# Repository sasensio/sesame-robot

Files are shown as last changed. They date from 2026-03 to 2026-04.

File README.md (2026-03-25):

# The Sesame Robot Project 
___







sesame-cover

<p align="center">
  <a href="https://www.youtube.com/watch?v=NIgoQVQF_Ng">
    tutorial-button
  </a>
</p>

___

**Greetings, from your new best friend.**

Sesame is an accessible Open-Source robotics project based on the ESP32 microcontroller system, with an emphasis on expression and movement. 
This project is designed for makers and engineers of all skill levels! Sesame offers a dynamic platform designed to start working with walking robots. 
To build a sesame robot, you will need basic soldering skills, $50-60 in hardware components, access to a 3D printer, and a basic understanding of Arduino IDE.

This repository contains the CAD design files, STL files, build and wiring guides, and the base/expanded firmware for the ESP32-based controller. 
There is also some included debugging firmware that may be helpful in getting your Sesame up and running.

## Features

*   **Quadruped Design:** Uses 8 servo motors (2 per leg) to achieve roughly 8 total degrees of freedom.
*   **Emotive Display:** Features a 128x64 OLED screen acting as a reactive face that syncs with movement.
*   **Fully Printable:** Designed entirely for 3D printing in PLA with minimal supports.
*   **Network Connectivity:** Connect to your WiFi network for remote control and API access.
*   **JSON API:** RESTful API for programmatic control from Python, JavaScript, and more.
*   **Conversational Faces:** Expressive emotion library with talk variants for voice assistant projects.
*   **Sesame Studio:** New animation composer software to easily create custom movements.
*   **Sesame Companion App:** Python application for voice control and advanced interactions.
*   **Serial CLI:** Control the robot and trigger animations via a Serial Command Line Interface or the web UI.
*   **Pre-programmed Emotes:** Includes animations for Walking, Waving, Dancing, Pointing, Resting, and more.

## Watch the launch video on YouTube

<a href="https://www.youtube.com/watch?v=1UDsWkcQZhc">thumb-youtube</a>

## Join the Discord community
[https://discord.gg/JcFEPBbtEj
](https://discord.gg/JcFEPBbtEj)
___

## Getting Started

Follow these steps to build your own Sesame Robot:

### 1. Gather Parts 
Check the **[Bill of Materials (BOM)](hardware/bom/README.md)** for a complete list of required electronics and hardware.
*   Microcontroller: Lolin S2 Mini (recommended for DIY builds), Sesame Distro Board V2 (included in Build Kits, pre-flashed), or ESP32-DevKitC-32E with Distro Board V1 (legacy)
*   Actuators: 8x MG90 Servos
*   Power: 5V 3A source (USB-C PD for S2 Mini and V2 Distro Board, or battery + buck converter; see BOM for the 2× 10440 Li-ion + 2× AAA holder option)

### 2. Print Parts 
Download the STLs and follow the **[Printing Guide](hardware/printing/README.md)**.
*   Designed for PLA
*   Minimal supports required

### 3. Build & Wire 
Follow the **[Build Guide](docs/build-guide/README.md)** and **[Wiring Guide](docs/wiring-guide/README.md)** to assemble the frame and connect the electronics.

### 4. Flash Firmware 
Upload the code from the **[Firmware Directory](firmware/README.md)**.
*   Requires Arduino IDE
*   Configure WiFi AP settings

### 5. Create Animations 
Use **[Sesame Studio](software/sesame-studio/README.md)** to visually design poses and sequences for your robot.

sesame-wakeup-gif

---

## Software & Firmware

### Sesame Studio
Sesame Studio is a standalone desktop application included in `software/sesame-studio/`. It allows you to:
*   Visually pose the robot using a schematic interface.
*   Generate C++ code for servo angles automatically.
*   Sequence frames into complex animations.

[**> Go to Sesame Studio**](software/sesame-studio/README.md)

sesamestudio-preview

### Sesame Companion App
The Sesame Companion App is a Python-based application that enables advanced control and interaction with your robot over your local network. It leverages the new JSON API and network mode features to provide:
*   **Voice Assistant Integration:** Control Sesame with voice commands and see real-time emotional expressions.
*   **Remote Control:** Command your robot from anywhere on your local network.
*   **Face Control:** Change expressions dynamically based on conversation or context.
*   **API Examples:** Reference implementation for building your own integrations.

The Companion App works with robots running the latest firmware with network mode enabled.

[**> Go to Sesame Companion App Repository**](https://github.com/dorianborian/sesame-companion-app)

### Firmware
The ESP32 firmware (`sesame-firmware-main.ino`) handles the kinematics, face display, and WiFi control interface.
*   **Web UI:** Control the robot from your phone via the built-in Access Point.
*   **Custom Faces:** Add your own bitmaps (guide in firmware docs).

[**> Go to Firmware Docs**](firmware/README.md)

firmware-preview

---

## Contributing

This robot is a platform for building new features, cosmetics, tools, and ideas. Since the current firmware is a basic implementation, pull requests are very welcome for:
*   Kinematics improvements
*   New animations
*   Improved Web UI/UX
*   Sensor integration (Ultrasonic, Gyro, etc.)

I would also love to see forks of this project with new hardware, software, faces, etc. Be sure to send me a message if you end up building one, and I might feature you on my website or channel!
  
---

## Sesame Complete Build Kit Pre-orders available!
I am excited to announce that, after popular demand, Sesame Complete Build Kits are now available for pre-order! 

That's right, your little robot companion just got even easier to build. Each kit includes all the components you need to build a full Sesame Robot. With the included detailed instructions, guides, and resources, this kit is perfect for both seasoned Makers and beginners. Click the image below to learn more.

<a href="https://www.doriantodd.com/sesame/kit">kits-availible</a>

---

*Created by [Dorian Todd](https://www.doriantodd.com/). Need help with your Sesame Robot? Send me a message on Discord, my username is "starphee"*

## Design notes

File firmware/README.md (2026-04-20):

# Sesame Robot Firmware

This document provides technical information on the firmware architecture, control logic, and hardware abstraction layers used in the Sesame Robot.

>[!NOTE]
> The firmware is now organized into a modular structure with a main entry point and specialized header files for bitmaps, movement, and web assets. This makes customization much easier and the codebase cleaner.

## Table of Contents

- [How to Flash the Firmware](#how-to-flash-the-firmware)
- [Network Configuration](#network-configuration--connectivity)
- [API Reference](#api-reference)
  - [Legacy Web Endpoints](#legacy-web-endpoints)
  - [JSON API](#json-api-recommended-for-network-clients)
  - [Python Examples](#python-api-example)
  - [JavaScript Examples](#nodejsjavascript-example)
- [Advanced Integration Examples](#advanced-integration-examples)
  - [Voice Assistant Integration](#voice-assistant-integration)
  - [Home Automation](#home-automation-integration)
- [Idle Animation System](#idle-animation-system)
- [Firmware Architecture](#firmware-architecture)
- [Technical Implementation](#technical-implementation-overview)
- [Asset Pipeline & Face Customization](#asset-pipeline--face-customization)
- [Hardware Abstraction Layer](#hardware-abstraction-layer-hal)

## How to Flash the Firmware

> [!NOTE]
> **Sesame Build Kit Users:** Your Distro Board V2 comes pre-flashed with the latest firmware. You only need to flash firmware if you want to customize it or update to a newer version.

### Prerequisites
1. **Arduino IDE** (version 2.0 or higher recommended)
2. **ESP32 Board Support**: Install via Arduino IDE's Board Manager
   - Open Arduino IDE
   - Go to **File → Preferences**
   - Add to "Additional Board Manager URLs": `https://raw.githubusercontent.com/espressif/arduino-esp32/gh-pages/package_esp32_index.json`
   - Go to **Tools → Board → Boards Manager**
   - Search for "ESP32" and install "ESP32 by Espressif Systems" (v2.0.0 or higher)
3. **Required Libraries** (install via Library Manager):
   - `Adafruit SSD1306`
   - `Adafruit GFX Library`
   - **For direct-PWM boards** (Lolin S2 Mini, Distro Board V1/V2):
     - `ESP32Servo` **v3.0.9** (recommended)
   - **For camera boards** (ESP32-CAM, ESP32-S3-CAM):
     - `Adafruit PWM Servo Driver Library` (`Adafruit_PWMServoDriver`)

> [!IMPORTANT]
> Use **ESP32Servo v3.0.9** for direct-PWM boards. Newer releases currently have a known issue where writing to one servo can affect multiple channels ([madhephaestus/ESP32Servo#103](https://github.com/madhephaestus/ESP32Servo/issues/103)).
> Camera boards (ESP32-CAM, ESP32-S3-CAM) use PCA9685 instead of ESP32Servo and are not affected.

### Flashing Steps
1. **Connect your board** via USB to your computer
2. **Open the firmware**:
   - Open [sesame-firmware-main.ino](sesame-firmware-main.ino) in Arduino IDE
   - Make sure you have it in a folder with the same name.
   - Also include all of the .h header files.
3. **Select your board**:
   - Go to **Tools → Board**
   - For Lolin S2 Mini: Select "LOLIN S2 Mini"
   - For Sesame Distro Board V1: Select "ESP32 Dev Module"
   - For Sesame Distro Board V2: Select "ESP32S3 Dev Module"
   - **For ESP32-CAM**: Select "AI Thinker ESP32-CAM"
   - **For ESP32-S3-CAM**: Select "ESP32S3 Dev Module" (or the specific module variant)
4. **Configure board settings**:
   - **For Lolin S2 Mini**:
     - **Upload Speed**: 921600
     - **USB CDC On Boot**: "Enabled"
     - **Partition Scheme**: "Default 4MB with spiffs"
   - **For Distro Board V2 (ESP32-S3)**:
     - **USB CDC On Boot**: "Enabled" (Required for Serial Monitor)
     - **Flash Mode**: "QIO 80MHz"
     - **Partition Scheme**: "Default 4MB with spiffs"
   - **For ESP32-CAM**:
     - **Upload Speed**: 115200
     - **Flash Mode**: "DIO"
     - **Partition Scheme**: "Huge APP (3MB No OTA/1MB SPIFFS)"
5. **Select the correct port**:
   - Go to **Tools → Port** and select your ESP32's COM port
6. **Choose your board configuration** in the code:
   - Open [sesame-firmware-main.ino](sesame-firmware-main.ino)
   - Find the **Board Selection** block at the very top of the file (lines 1-10)
   - Uncomment **only** the `#define` that matches your board (leave the rest commented):
     ```cpp
     // #define BOARD_ESP32CAM        // AI-Thinker ESP32-CAM
     // #define BOARD_ESP32S3CAM      // Generic ESP32-S3-CAM (placeholder)
     // #define BOARD_DISTRO_V2       // Sesame Distro Board V2
     // #define BOARD_DISTRO_V1       // Sesame Distro Board V1
     // (leave all commented = Lolin S2 Mini default)
     ```
   - For camera boards (ESP32-CAM, ESP32-S3-CAM) also attach a **PCA9685** breakout to GPIO 26 (SDA) / GPIO 27 (SCL) — see [hal/README.md](hal/README.md) for wiring details.
7. **(Optional) Configure network mode**:
   - If you want the robot to connect to your WiFi network (for API access and remote control), edit the network configuration section (around line 17-22):
   ```cpp
   #define NETWORK_SSID "YourNetworkName"  // Your WiFi network name
   #define NETWORK_PASS "YourPassword"     // Your WiFi password
   #define ENABLE_NETWORK_MODE true        // Set to true to enable
   ```
   - Leave `ENABLE_NETWORK_MODE false` to use Access Point mode only
8. **Upload the firmware**:
   - Click the **Upload** button (→) in Arduino IDE
   - Wait for compilation and upload to complete
9. **Test the connection**:
   - Open Serial Monitor (**Tools → Serial Monitor**, set baud rate to 115200)
   - Reset the board - you should see startup messages and network information
   - The serial monitor provides individual motor control for testing and troubleshooting
   - **If using AP mode only**: Connect to the "Sesame-Controller-BETA" WiFi network (password: `12345678`) and navigate to any website
   - **If using network mode**: Look for the "Connected to network!" message in Serial Monitor, then access via `http://sesame-robot.local` or the displayed IP address

### Troubleshooting
- **Linux USB Permissions**: If your port isn't showing up or you get "Permission Denied", you likely need to add your user to the `dialout` group: `sudo usermod -a -G dialout $USER`. Log out and back in for changes to take effect.
- **Upload fails**: Try holding the BOOT button while uploading, or try a different USB cable. For S3-based boards, the "USB CDC On Boot" setting is critical for finding the port after a reset.
- **Port not found**: Install the appropriate USB drivers (CP210x for S2 Mini, CH340 for some ESP32 boards). Windows 10/11 usually includes these.
- **Robot not moving**: Check power supply and servo connections; increase `motorCurrentDelay` in web settings if brownouts occur
- **Can't connect to network**: 
  - Verify `ENABLE_NETWORK_MODE` is set to `true` and SSID/password are correct
  - Check Serial Monitor for connection status - look for "Connected to network!" or error messages
  - Ensure your WiFi network is 2.4GHz (ESP32 does not support 5GHz)
  - Try increasing the connection timeout in the code (currently 10 seconds / 20 attempts)
- **mDNS hostname not resolving**:
  - On Windows, install [Bonjour Print Services](https://support.apple.com/kb/DL999)
  - On Linux, ensure `avahi-daemon` is installed and running
  - Try accessing via IP address instead (check Serial Monitor for the assigned IP)
  - Some routers block mDNS traffic - check router settings or use IP address
- **API commands not working**:
  - Ensure you're sending POST requests to `/api/command` (not GET)
  - Verify `Content-Type: application/json` header is set
  - Check Serial Monitor for error messages and parsed command output
  - Test with a simple cURL command first to verify connectivity

## Firmware Architecture

The firmware is split into several key files to keep the logic organized and assets easy to manage:

- **[sesame-firmware-main.ino](sesame-firmware-main.ino)**: The main entry point containing the `setup()`, `loop()`, core system logic, network configuration, and API endpoints.
- **[face-bitmaps.h](face-bitmaps.h)**: A dedicated header for OLED face macros and raw bitmap data. Now includes extensive conversational faces for voice assistant integration.
- **[movement-sequences.h](movement-sequences.h)**: Definitions for all procedural movement and pose animations.
- **[captive-portal.h](captive-portal.h)**: Contains the HTML, CSS, and JS for the web-based remote control interface.

## Technical Implementation Overview

The firmware is built on the Arduino-ESP32 framework. Currently the firmware is running on a single-core event loop, and hardware-based PWM timers for precise motor control.

### PWM & Servo Kinematics
- **Timer Allocation**: The firmware uses `ESP32PWM::allocateTimer(n)` to reserve hardware timers 0-3. This prevents conflicts with other peripherals and ensuring high-resolution PWM signals (50Hz frequency). Due to the limited number of timers, you may experience network errors upon adding additional devices or calls to the firmware. For example, in a modded version of the robot, I tried adding two ESCs and their servo controll to the code, and the CPU ran out of internal timers and caused the captive portal to die. If you are experiencing network errors with your custom firmware, check the timer allocation.
- **Pulse Width Mapping**: Leg servos are mapped from degrees (0-180) to microseconds (732us to 2929us). This range is set to the maximum travel on most hobby servos with a 180 degree limit, but can be edited in the `servos[i].attach()` calls. If you are using motors with a larger range of motion, like 270 degree servos, you need to set the PWM mapping to a different length of microseconds. For 270 degree servos specifically I found (833us to 2167us) works.
- **Staggered Activation**: To prevent VCC rail collapse (brownout) caused by simultaneous inductive loads, the `setServoAngle` helper introduces a mandatory `motorCurrentDelay` (default 20ms) between sequential pulses. This delay should be tweaked to your power setup. If you have a strong dedicated power supply you can try setting it to zero. It can also be changed while running through the AP controller settings menu.
- **PCA9685 Auto-Release (Optional)**: For camera boards, `ENABLE_SERVO_AUTO_RELEASE` can release PWM outputs in rest mode to reduce idle servo current draw. This lowers holding power usage at the cost of holding torque while resting.

### Camera Stream & Recovery
- **Toggle Recovery Path**: Turning the camera OFF deinitializes and powers down the camera driver; turning it ON powers up, reinitializes with retries, and validates frame capture before stream resume.
- **Web Reconnect Robustness**: The web UI reconnects MJPEG with cache-busted URLs and retry cleanup to avoid stale stream sessions when toggling OFF→ON.
- **Adaptive FPS Hold**: Camera active frame timing now remains in high-rate mode for 30 seconds after movement stops, then returns to idle-rate streaming.
- **On-Board LED Control**: ESP32-CAM flash LED can be toggled from the web UI when supported by the selected board HAL.

### Communication & Networking Stack
- **Dual-Mode WiFi**: The ESP32 can simultaneously operate in both Access Point mode (for direct connections) and Station mode (connected to an existing network) using `WiFi.mode(WIFI_AP_STA)`.
- **SoftAP & Captive Portal**: The ESP32 initializes an Access Point using `WiFi.softAP()`. A `DNSServer` listens on UDP Port 53, using a wildcard "*" redirect to map all DNS queries to the internal gateway (`192.168.4.1`).
- **mDNS Service Discovery**: The firmware broadcasts `sesame-robot.local` via Multicast DNS (mDNS) using the `ESPmDNS` library, allowing network discovery without hardcoded IP addresses.
- **RESTful API Surface**: The `WebServer` handles both legacy URL-parameter endpoints and modern JSON-based API:
  - `/cmd?go=[dir]`: Legacy movement control
  - `/cmd?pose=[name]`: Legacy pose triggers
  - `/api/status`: JSON status endpoint (GET)
  - `/api/command`: JSON command endpoint (POST) - supports face-only updates and combined face+movement commands
  - `/getSettings` / `/setSettings`: Parameter configuration
- **Face-Only Command Support**: The `/api/command` endpoint intelligently detects face-only requests (no `command` field) and updates the display without triggering movement animations.
- **Non-Blocking Control Flow**: Instead of `delay()`, the firmware uses a custom `pressingCheck(String cmd, int ms)` function. This function polls `server.handleClient()` and `dnsServer.processNextRequest()` during animation frames, allowing for real-time interruptibility (e.g., immediate stop on button release). This pressingCheck protocol can be used for motion commands like walking to play each motion only when the button is held.

### Display & Graphics Subsystem
- **I2C Bus Hardware**: Utilizes the ESP32's hardware I2C controller at 400kHz (Fast Mode) for minimal latency when pushing full-frame buffers to the SSD1306 display.
- **Memory Management (`PROGMEM`)**: Large 128x64 bitmap arrays (1024 bytes per frame) are stored in Flash memory using the `PROGMEM` attribute.
- **Macro-Based Asset Management**: The firmware uses a `FACE_LIST` macro in [face-bitmaps.h](face-bitmaps.h) to automatically register and handle new faces, reducing the boilerplate required when adding animations.
- **Rendering Pipeline**: The `updateAnimatedFace()` function manages frame rates and sequence looping outside of the main movement logic to ensure smooth visual feedback even during complex movements.
- **Dynamic WiFi Info Overlay**: The `updateWifiInfoScroll()` function composites scrolling connection information over the face bitmap during the first 30 seconds of operation (before first input), drawing the face as background with a black bar and white text overlay for readability.
- **Idle Animation System**: Implements realistic idle behavior with randomized blinking (including double-blinks) and boomerang face animations, triggered automatically when no input is detected.

## Prerequisites & Development Environment

- **Board Support**: ESP32 by Espressif Systems (v2.0.0+ recommended). Lolin S2 Mini and ESP32-WROOM32 DevKitC are best supported.
- **Libraries**:
  - `ESP32Servo` **v3.0.9**: Low-level PWM timer management. (Pinned due to known multi-servo command leak in newer versions: [madhephaestus/ESP32Servo#103](https://github.com/madhephaestus/ESP32Servo/issues/103))
  - `Adafruit_SSD1306` & `Adafruit_GFX`: Buffer-based OLED rendering.
  - `ESPmDNS`: mDNS service discovery (included with ESP32 board support).
  - `DNSServer`: Captive portal DNS redirection (included with ESP32 board support).
  - `WebServer`: HTTP server implementation (included with ESP32 board support).
- **Tooling**: Arduino IDE 2.0+ recommended.

## Network Configuration & Connectivity

The firmware now supports **dual-mode WiFi operation**, allowing the robot to simultaneously act as an Access Point (for direct connections) and connect to your existing WiFi network (for integration with other devices and remote control).

### Access Point Mode (Default)
By default, the robot creates its own WiFi network:
- **SSID**: `Sesame-Controller-BETA`
- **Password**: `12345678` (Some devices may require you to change this if the default isn't connecting)
- **IP Address**: `192.168.4.1`

Connect to this network and navigate to any website to access the captive portal control interface. If you're having trouble connecting, try changing the password to something custom in the code's `#define AP_PASS` section.

### Network Mode (Optional)
To connect the robot to your home or office WiFi network:

1. **Enable Network Mode** in [sesame-firmware-main.ino](sesame-firmware-main.ino):
   ```cpp
   #define NETWORK_SSID "YourNetworkName"  // Your WiFi network name
   #define NETWORK_PASS "YourPassword"     // Your WiFi password
   #define ENABLE_NETWORK_MODE true        // Set to true to enable
   ```

2. **Flash the updated firmware** to your robot.

3. **Access via multiple methods**:
   - **mDNS Hostname**: `http://sesame-robot.local` (works on most devices)
   - **Network IP**: Check Serial Monitor at 115200 baud for the assigned IP address
   - **Still accessible via AP**: The robot maintains its Access Point even when connected to your network

### mDNS Discovery
The firmware includes an mDNS responder that broadcasts the hostname `sesame-robot.local` on your local network. This allows you to access the robot without knowing its IP address:

```bash
# Access from browser
http://sesame-robot.local

# Ping test
ping sesame-robot.local
```

**Note**: mDNS works natively on:
- macOS and iOS devices
- Linux with Avahi installed
- Windows 10+ (may require Bonjour service)

### Security Considerations

The firmware is designed for local network use and does not include authentication by default. When enabling network mode:

- **Local Network Only**: The robot responds to requests from any device on your network. Do not expose it to the internet without proper security measures.
- **No HTTPS**: Communication is unencrypted HTTP. Avoid transmitting sensitive data through the robot's API.
- **Access Point Password**: The default AP password is `12345678`. For production use, change `AP_PASS` in the firmware to a stronger password.
- **Trusted Networks**: Only connect your robot to trusted WiFi networks.

For enhanced security:
1. Change the default AP password to a strong, unique password
2. Use network segmentation (IoT VLAN) to isolate the robot from critical devices
3. Implement firewall rules to restrict access to specific IP addresses
4. Consider adding authentication headers in a custom firmware fork for production deployments

### WiFi Information Display
The robot's OLED screen now features an intelligent WiFi info system:
- **First 30 seconds**: If no input is received, WiFi connection information scrolls across the top of the display
- **After first input**: WiFi info disappears to show only faces
- **Dual-mode info**: When connected to both AP and network, displays both connection details

The scrolling text includes:
- Access Point SSID and IP
- Network name and IP (if connected)
- mDNS hostname
- Captive portal instructions

## API Reference

The firmware exposes both legacy web endpoints and a modern JSON-based API for programmatic control.

### Legacy Web Endpoints

These endpoints use URL parameters and are primarily used by the web interface:

#### Movement Control
```http
GET /cmd?go=forward
GET /cmd?go=backward
GET /cmd?go=left
GET /cmd?go=right
GET /cmd?stop
```

#### Pose Control
```http
GET /cmd?pose=wave
GET /cmd?pose=dance
GET /cmd?pose=rest
GET /cmd?pose=stand
# ... (see movement-sequences.h for all available poses)
```

#### Individual Motor Control
```http
GET /cmd?motor=1&value=90
# motor: 1-8 (motor number)
# value: 0-180 (angle in degrees)
```

#### Settings Management
```http
GET /getSettings
# Returns: {"frameDelay":100,"walkCycles":10,"motorCurrentDelay":20,"faceFps":8,
#           "cameraEnabled":true,"cameraLed":false,"cameraLedAvailable":true}

GET /setSettings?frameDelay=120&walkCycles=15&motorCurrentDelay=25&faceFps=10

# Camera controls
GET /setSettings?camera=1
GET /setSettings?camera=0

# Camera LED controls (when available)
GET /setSettings?camLed=1
GET /setSettings?camLed=0
```

### JSON API (Recommended for Network Clients)

The JSON API is designed for programmatic control from external devices, Python scripts, and IoT integrations.

#### Get Robot Status
```http
GET /api/status
```

**Response:**
```json
{
  "currentCommand": "forward",
  "currentFace": "walk",
  "networkConnected": true,
  "apIP": "192.168.4.1",
  "networkIP": "192.168.1.100"
}
```

#### Send Commands
```http
POST /api/command
Content-Type: application/json

{
  "command": "forward",
  "face": "walk"
}
```

**Response:**
```json
{
  "status": "ok",
  "message": "Command executed"
}
```

#### Face-Only Updates
Send a face change without triggering movement:

```http
POST /api/command
Content-Type: application/json

{
  "face": "happy"
}
```

**Response:**
```json
{
  "status": "ok",
  "message": "Face updated"
}
```

#### Stop Command
```http
POST /api/command
Content-Type: application/json

{
  "command": "stop"
}
```

### Available Commands

**Movement Commands:**
- `forward`, `backward`, `left`, `right` - Continuous movement (loops until stopped)
- `stop` - Immediately stop current movement

**Pose Commands (one-shot animations):**
- `rest`, `stand`, `wave`, `dance`, `swim`, `point`
- `pushup`, `bow`, `cute`, `freaky`, `worm`, `shake`
- `shrug`, `dead`, `crab`

**Available Faces:**
- Movement faces: `walk`, `rest`, `stand`, `dance`, `wave`, etc.
- Conversational faces: `happy`, `sad`, `angry`, `surprised`, `sleepy`, `love`, `excited`, `confused`, `thinking`
- Talk variants: `talk_happy`, `talk_sad`, `talk_angry`, etc.
- Special: `idle`, `idle_blink`, `default`

### Python API Example

```python
import requests
import time

# Robot IP or hostname
robot_url = "http://sesame-robot.local"

# Get status
response = requests.get(f"{robot_url}/api/status")
status = response.json()
print(f"Current face: {status['currentFace']}")

# Make robot wave and show happy face
requests.post(f"{robot_url}/api/command", json={
    "command": "wave",
    "face": "happy"
})

time.sleep(3)

# Just change face without moving
requests.post(f"{robot_url}/api/command", json={
    "face": "excited"
})

# Stop movement
requests.post(f"{robot_url}/api/command", json={
    "command": "stop"
})
```

### cURL Examples

```bash
# Get robot status
curl http://sesame-robot.local/api/status

# Make robot dance
curl -X POST http://sesame-robot.local/api/command \
  -H "Content-Type: application/json" \
  -d '{"command":"dance","face":"dance"}'

# Change face only
curl -X POST http://sesame-robot.local/api/command \
  -H "Content-Type: application/json" \
  -d '{"face":"happy"}'

# Stop movement
curl -X POST http://sesame-robot.local/api/command \
  -H "Content-Type: application/json" \
  -d '{"command":"stop"}'
```

### Node.js/JavaScript Example

```javascript
const robotURL = 'http://sesame-robot.local';

// Get status
fetch(`${robotURL}/api/status`)
  .then(res => res.json())
  .then(data => console.log('Robot status:', data));

// Send command
fetch(`${robotURL}/api/command`, {
  method: 'POST',
  headers: {'Content-Type': 'application/json'},
  body: JSON.stringify({
    command: 'wave',
    face: 'happy'
  })
})
.then(res => res.json())
.then(data => console.log('Response:', data));

// Face-only update
fetch(`${robotURL}/api/command`, {
  method: 'POST',
  headers: {'Content-Type': 'application/json'},
  body: JSON.stringify({face: 'surprised'})
})
.then(res => res.json())
.then(data => console.log('Response:', data));
```

## Advanced Integration Examples

### Voice Assistant Integration

The combination of conversational faces, the JSON API, and network mode makes the Sesame Robot perfect for voice assistant projects. Here's an example using Python with speech recognition:

```python
import requests
import speech_recognition as sr
from textblob import TextBlob
import time

robot_url = "http://sesame-robot.local"

def analyze_sentiment(text):
    """Analyze sentiment and return appropriate face"""
    blob = TextBlob(text)
    polarity = blob.sentiment.polarity
    
    if polarity > 0.5:
        return "excited"
    elif polarity > 0.2:
        return "happy"
    elif polarity < -0.5:
        return "angry"
    elif polarity < -0.2:
        return "sad"
    else:
        return "thinking"

def set_robot_face(face, talking=False):
    """Update robot's face expression"""
    if talking:
        face = f"talk_{face}"
    
    requests.post(f"{robot_url}/api/command", json={"face": face})

# Initialize speech recognition
recognizer = sr.Recognizer()

while True:
    with sr.Microphone() as source:
        print("Listening...")
        set_robot_face("idle")
        
        try:
            audio = recognizer.listen(source, timeout=5)
            set_robot_face("thinking")
            
            text = recognizer.recognize_google(audio)
            print(f"You said: {text}")
            
            # Determine emotion and show talking face
            emotion = analyze_sentiment(text)
            set_robot_face(emotion, talking=True)
            
            # Process command...
            time.sleep(2)
            
            # Return to neutral
            set_robot_face(emotion, talking=False)
            
        except sr.WaitTimeoutError:
            set_robot_face("sleepy")
        except sr.UnknownValueError:
            set_robot_face("confused")
```

### Home Automation Integration

Integrate with Home Assistant or other home automation platforms:

```python
# Home Assistant automation example
import requests

def robot_notification(message_type):
    """Display robot emotion based on notification type"""
    robot_url = "http://sesame-robot.local"
    
    emotion_map = {
        "doorbell": "surprised",
        "alarm": "angry",
        "reminder": "thinking",
        "success": "happy",
        "error": "sad"
    }
    
    face = emotion_map.get(message_type, "default")
    requests.post(f"{robot_url}/api/command", json={"face": face})
    
    # Optional: add movement
    if message_type == "doorbell":
        requests.post(f"{robot_url}/api/command", json={
            "command": "wave",
            "face": "happy"
        })
```

### WebSocket Streaming (Advanced)

For real-time control with minimal latency, you can poll the status endpoint or implement a simple state machine:

```javascript
// React/Vue.js real-time robot control
class RobotController {
  constructor(robotURL) {
    this.url = robotURL;
    this.currentFace = 'default';
  }
  
  async updateEmotion(emotion, isSpeaking) {
    const face = isSpeaking ? `talk_${emotion}` : emotion;
    
    if (face !== this.currentFace) {
      await fetch(`${this.url}/api/command`, {
        method: 'POST',
        headers: {'Content-Type': 'application/json'},
        body: JSON.stringify({face})
      });
      
      this.currentFace = face;
    }
  }
  
  async getStatus() {
    const res = await fetch(`${this.url}/api/status`);
    return await res.json();
  }
  
  async performAction(action, emotion = null) {
    const payload = {command: action};
    if (emotion) payload.face = emotion;
    
    await fetch(`${this.url}/api/command`, {
      method: 'POST',
      headers: {'Content-Type': 'application/json'},
      body: JSON.stringify(payload)
    });
  }
}

// Usage
const robot = new RobotController('http://sesame-robot.local');

// Set emotion without moving
await robot.updateEmotion('happy', false);

// Set talking face
await robot.updateEmotion('excited', true);

// Perform action with face
await robot.performAction('dance', 'excited');

// Check status
const status = await robot.getStatus();
console.log(`Robot is ${status.currentFace} and doing ${status.currentCommand}`);
```

## Idle Animation System

The firmware includes an intelligent idle animation system that activates automatically:

### Behavior
- **Activation**: When the robot has received no commands for a period, it enters idle mode
- **Idle Face**: Displays a gentle "breathing" animation using the `idle` face in `FACE_ANIM_BOOMERANG` mode
- **Blinking**: Randomly triggers blink animations (3-7 second intervals)
- **Double Blinks**: 30% chance of a double blink for realistic behavior
- **Exit**: Any movement command or input immediately exits idle mode

### Technical Implementation
The idle system uses:
- `enterIdle()` - Activates idle face with boomerang animation
- `exitIdle()` - Returns to normal operation
- `updateIdleBlink()` - Manages random blink timing and double-blink logic
- `scheduleNextIdleBlink()` - Randomizes blink intervals for natural appearance

To customize idle behavior, modify the timing values in [sesame-firmware-main.ino](sesame-firmware-main.ino):
```cpp
scheduleNextIdleBlink(3000, 7000);  // Min and max ms between blinks
```

## Asset Pipeline & Face Customization

The firmware includes an intelligent idle animation system that activates automatically:

### Behavior
- **Activation**: When the robot has received no commands for a period, it enters idle mode
- **Idle Face**: Displays a gentle "breathing" animation using the `idle` face in `FACE_ANIM_BOOMERANG` mode
- **Blinking**: Randomly triggers blink animations (3-7 second intervals)
- **Double Blinks**: 30% chance of a double blink for realistic behavior
- **Exit**: Any movement command or input immediately exits idle mode

### Technical Implementation
The idle system uses:
- `enterIdle()` - Activates idle face with boomerang animation
- `exitIdle()` - Returns to normal operation
- `updateIdleBlink()` - Manages random blink timing and double-blink logic
- `scheduleNextIdleBlink()` - Randomizes blink intervals for natural appearance

To customize idle behavior, modify the timing values in [sesame-firmware-main.ino](sesame-firmware-main.ino):
```cpp
scheduleNextIdleBlink(3000, 7000);  // Min and max ms between blinks
```

## Hardware Abstraction Layer (HAL)

Pin and peripheral definitions are now centralized in the [`hal/`](hal/) folder.  Including `hal/hal.h` selects the correct configuration based on the `BOARD_*` macro defined at the top of `sesame-firmware-main.ino`.  See **[hal/README.md](hal/README.md)** for full wiring details and rationale.

### Pin Configuration Tables

#### Lolin S2 Mini (ESP32-S2) — `BOARD_LOLIN_S2_MINI` (default)

| Motor/Component | Array Index | GPIO Pin | Notes |
|---|---|---|---|
| Motor 0 | 0 | 1 | R1 |
| Motor 1 | 1 | 2 | R2 |
| Motor 2 | 2 | 4 | L1 |
| Motor 3 | 3 | 6 | L2 |
| Motor 4 | 4 | 8 | R4 |
| Motor 5 | 5 | 10 | R3 |
| Motor 6 | 6 | 13 | L3 |
| Motor 7 | 7 | 14 | L4 |
| **I2C SDA** | - | **33** | SSD1306 Data (Hardware I2C) |
| **I2C SCL** | - | **35** | SSD1306 Clock (Hardware I2C) |

#### Sesame Distro Board V1 & V2 (ESP32-WROOM32) — `BOARD_DISTRO_V1` / `BOARD_DISTRO_V2`

> [!NOTE]
> Both V1 and V2 Distro Boards use the same pin configuration.

| Motor/Component | Array Index | GPIO Pin | Notes |
|---|---|---|---|
| Motor 0 | 0 | 15 | R1 |
| Motor 1 | 1 | 2 | R2 |
| Motor 2 | 2 | 23 | L1 |
| Motor 3 | 3 | 19 | L2 |
| Motor 4 | 4 | 4 | R4 |
| Motor 5 | 5 | 16 | R3 |
| Motor 6 | 6 | 17 | L3 |
| Motor 7 | 7 | 18 | L4 |
| **I2C SDA** | - | **21** | SSD1306 Data (Hardware I2C) |
| **I2C SCL** | - | **22** | SSD1306 Clock (Hardware I2C) |

#### AI-Thinker ESP32-CAM — `BOARD_ESP32CAM`

Servos are driven via a **PCA9685** I2C PWM driver.  GPIO 26/27 (camera SCCB) are internal to the PCB and not exposed on the headers, so I2C is placed on **GPIO 14 (SDA) / GPIO 15 (SCL)** — the only header-accessible pins without boot-strapping conflicts.

| Component | GPIO / Value | Notes |
|---|---|---|
| **I2C SDA** | **14** | J3 header — SD_CLK repurposed for I2C |
| **I2C SCL** | **15** | J3 header — SD_CMD repurposed; built-in pull-up ensures HIGH at boot |
| PCA9685 address | 0x40 | Default (A0–A5 all LOW) |
| PCA9685 ch 0–7  | — | R1–L4 servo outputs |
| CAM LED | 4 | On-board flash LED; web-toggle capable |
| SD_DATA0 | 2 | Preserved — not used by HAL |
| SD_DATA1 | 4 | Preserved — not used by HAL |
| SD_DATA2 | 12 | Preserved — not used by HAL |
| SD_DATA3 | 13 | Preserved — not used by HAL |
| SD_CLK | 14 | **Used as I2C SDA** — SD and I2C are mutually exclusive |
| SD_CMD | 15 | **Used as I2C SCL** — SD and I2C are mutually exclusive |

#### Generic ESP32-S3-CAM — `BOARD_ESP32S3CAM` (placeholder)

> [!WARNING]
> This is a placeholder — verify GPIO numbers against your specific board's schematic.

| Component | GPIO / Value | Notes |
|---|---|---|
| **I2C SDA** | **8** | Common ESP32-S3 default — update if needed |
| **I2C SCL** | **9** | Common ESP32-S3 default — update if needed |
| PCA9685 address | 0x40 | Default (A0–A5 all LOW) |
| PCA9685 ch 0–7  | — | R1–L4 servo outputs |

### Adding Support for a New Board

To port to a new ESP32 variant, add a new `board_<name>.h` header inside the `hal/` folder defining `I2C_SDA`, `I2C_SCL`, and `USE_PCA9685`, then register it in `hal/hal.h`.  Ensure the chosen pins are output-capable, not strapping-critical, and not shared with peripherals already in use.

### Porting to Other ESP32 Variants

To port this to a different ESP32 variant, add a new board header in `hal/` and uncomment the matching `BOARD_*` define at the top of [sesame-firmware-main.ino](sesame-firmware-main.ino). Ensure the chosen pins are PWM-capable (for direct servo boards) or output-capable (for PCA9685 boards) and not "input-only".

## Asset Pipeline & Face Customization

To maintain a clean main source file and optimize performance, face bitmaps are decoupled from the primary logic. Faces are managed in [face-bitmaps.h](face-bitmaps.h) using a "Single Source of Truth" macro system.

### Face Library

The firmware includes an extensive library of faces organized into three categories:

#### Movement Faces
Synchronized with physical poses and animations:
- `walk`, `rest`, `stand`, `swim`, `dance`, `wave`, `point`
- `pushup`, `bow`, `cute`, `freaky`, `worm`, `shake`, `shrug`
- `dead`, `crab`, `idle`, `idle_blink`

#### Conversational Faces
Designed for expressive communication and voice assistant integration:
- **Base emotions**: `happy`, `sad`, `angry`, `surprised`, `sleepy`, `love`, `excited`, `confused`, `thinking`
- **Talk variants**: `talk_happy`, `talk_sad`, `talk_angry`, `talk_surprised`, `talk_sleepy`, `talk_love`, `talk_excited`, `talk_confused`, `talk_thinking`

The "talk_" variants feature open mouths for lip-sync and animated speech. These faces are perfect for:
- Voice assistant projects (Alexa, Google Assistant, custom TTS)
- Chatbot interfaces controlled via the JSON API
- Interactive storytelling and educational applications
- Remote-controlled performances

#### Special Faces
- `default` - The startup/fallback face
- `idle` - Gentle breathing animation for idle state
- `idle_blink` - Blink animation triggered randomly during idle

### Adding Custom Faces

### Workflow:
1.  **Image Creation**: Find faces using Kaomoji or [Emojicombos](https://emojicombos.com/kaomoji). Create a `128x64` image in a tool like [jsPaint](https://jspaint.app/).
2.  **Bitmap Conversion**: Use [image2cpp](https://javl.github.io/image2cpp/) with `Horizontal` scaling, `128x64` resolution, and `Arduino Code` output.
3.  **Registration**:
    -   Add your face name to the `FACE_LIST` macro in [face-bitmaps.h](face-bitmaps.h).
    -   Paste the generated C array into [face-bitmaps.h](face-bitmaps.h) right after the last bitmap in the list.
    -   (Optional) For animations, add numbered suffixes (e.g., `_1`, `_2`) and register the FPS in the `faceFpsEntries` in [sesame-firmware-main.ino](sesame-firmware-main.ino).

### Animating Faces
For an animation to be recognized by the `MAKE_FACE_FRAMES` macro, your array names in [face-bitmaps.h](face-bitmaps.h) must follow a strict naming convention:
- **Root Frame**: `epd_bitmap_myface` (This is required and acts as frame 0).
- **Subsequent Frames**: `epd_bitmap_myface_1`, `epd_bitmap_myface_2`, etc.
- **Limit**: The default system supports up to 6 frames per face (Root + 5 numbered frames).
- **Animation Modes**: Animations can be configured to play as a `LOOP` (restarts at frame 0), `ONCE` (stops on the final frame), or `BOOMERANG` (plays forward then reverses). These modes are typically defined in [movement-sequences.h](movement-sequences.h) when triggerring a pose.

### Macro System
The `FACE_LIST` macro uses X-Macros to automatically generate variable declarations and registration objects:
```cpp
#define FACE_LIST \
    X(walk) \
    X(rest) \
    X(my_new_face) // Just add this line!
```
This eliminates the need to manually update multiple switch statements or arrays when adding new assets.

## Execution & Deployment

1.  **Toolchain**: Configure your IDE for `ESP32 Dev Module` or `Lolin S2 Mini`.
2.  **Calibration**: Use the Serial Monitor (115200) to send manual step commands (e.g., `rn wf`).
3.  **Power Management**: If the robot brownouts during movement, increase `motorCurrentDelay` in the web settings to further stagger servo bursts.

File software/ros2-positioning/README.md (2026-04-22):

# micro-ROS + ArUco Positioning for Sesame Robot

This directory contains the host-side ROS 2 software that complements the
`esp32cam_ros` micro-ROS firmware running on the robot's ESP32-CAM.

## System Overview

```
┌─────────────────────────────────────────────────────────────────┐
│  Host Computer / Raspberry Pi 5                                  │
│                                                                  │
│  ┌─────────────────┐  ┌──────────────────┐  ┌───────────────┐  │
│  │ micro-ROS Agent │  │  aruco_node      │  │navigation_node│  │
│  │ (UDP port 8888) │◄─│  /camera/image   │─►│ /sesame/pose  │  │
│  └────────┬────────┘  │  → /sesame/pose  │  │ → /sesame/cmd │  │
│           │           └──────────────────┘  └───────────────┘  │
└───────────┼─────────────────────────────────────────────────────┘
            │  WiFi UDP (micro-XRCE-DDS)
            ▼
┌───────────────────────────────────────────────────────────────────┐
│  ESP32-CAM  (firmware: esp32cam_ros)                              │
│  Pub: /camera/image_raw  /sesame/status                           │
│  Sub: /sesame/cmd  /sesame/pose                                   │
└───────────────────────────────────────────────────────────────────┘
```

### What each piece does

| Component | Role |
|---|---|
| `esp32cam_ros` firmware | Publishes JPEG frames + status; subscribes to motion commands and pose |
| micro-ROS Agent | Bridges ESP32 micro-XRCE-DDS ↔ host ROS 2 DDS |
| `aruco_node` | Detects ArUco markers, estimates robot world pose |
| `navigation_node` | Proportional controller: drives robot through waypoints |

---

## Prerequisites

### Hardware
- AI-Thinker ESP32-CAM (or ESP32-S3-CAM) with PCA9685 servo driver
- Host: Ubuntu 22.04+ with ROS 2 Humble (or Raspberry Pi 5 with ROS 2)
- Printed ArUco markers (one on the robot, fixed ones in the environment)
- Shared WiFi network

### Software
```bash
# ROS 2 Humble
sudo apt install ros-humble-desktop

# Python dependencies for the ROS package
pip install opencv-python numpy pyyaml

# Or install via apt (recommended in ROS 2 environment)
sudo apt install python3-opencv python3-numpy python3-yaml
```

---

## Step 1: Flash the micro-ROS Firmware

```bash
# From the repo root
pio run -e esp32cam_ros -t upload
```

After flashing, open a serial terminal (115200 baud) to configure WiFi and
the agent IP:

```
set ssid  YourNetworkName
set pass  YourPassword
set agent 192.168.1.100       # IP of the computer running the micro-ROS agent
set port  8888
save
reboot
```

> **Note:** If the robot previously ran the standard firmware and WiFi
> credentials were saved, they are reused automatically (same NVS namespace).

---

## Step 2: Start the micro-ROS Agent

```bash
cd setup/
./install_agent.sh
```

Or run the agent directly with Docker:

```bash
docker run --rm --net=host \
  microros/micro-ros-agent:humble \
  udp4 --port 8888
```

Or natively (requires `ros-humble-micro-ros-agent`):

```bash
ros2 run micro_ros_agent micro_ros_agent udp4 --port 8888
```

Verify the ESP32 is connected:

```bash
ros2 topic list
# Should show: /camera/image_raw  /sesame/status  /sesame/cmd  /sesame/pose
```

---

## Step 3: Camera Calibration

Accurate pose estimation requires camera intrinsic calibration.

1. Print a 7×5 checkerboard with 25 mm squares.
2. Run the calibration script:

```bash
# Capture from /camera/image_raw while agent is running
python3 scripts/calibrate_camera.py --ros \
  --board-width 7 --board-height 5 --square-size 0.025 \
  --output config/camera_calibration.yaml
```

Move the checkerboard through 20+ diverse poses (tilt, rotate, different
distances) until the script completes.

---

## Step 4: Marker Setup

1. Print ArUco markers from `DICT_4X4_50` at a known physical size:

```python
import cv2.aruco as a, cv2
d = a.Dictionary_get(a.DICT_4X4_50)
# Marker 0 goes on the robot; 1, 2, 3 are fixed in the environment
for i in [0, 1, 2, 3]:
    img = a.drawMarker(d, i, 400)
    cv2.imwrite(f'marker_{i}.png', img)
```

2. Attach marker **ID 0** to the top of the Sesame Robot (visible from above).
3. Place markers **1, 2, 3** at known positions in the room.
4. Measure their world-frame positions (metres) and edit
   `config/marker_map.yaml`.

---

## Step 5: Build and Launch

```bash
# From the ros2-positioning directory (or your colcon workspace src/)
cd sesame_aruco/
colcon build --packages-select sesame_aruco
source install/local_setup.bash

# Launch everything (agent + detection + navigation)
ros2 launch sesame_aruco sesame_positioning.launch.py \
  camera_calibration_file:=$(pwd)/config/camera_calibration.yaml \
  marker_map_file:=$(pwd)/config/marker_map.yaml \
  marker_length:=0.10 \
  robot_marker_id:=0 \
  waypoints_file:=$(pwd)/config/waypoints.yaml
```

### Example waypoints.yaml

```yaml
waypoints:
  - x: 0.5
    y: 0.0
  - x: 0.5
    y: 0.5
  - x: 0.0
    y: 0.0
```

---

## Visualisation in rviz2

```bash
rviz2
```

Add these displays:
- **MarkerArray** → Topic: `/aruco/markers`
- **Path** → Topic: `/sesame/odom_path`
- **PoseStamped** → Topic: `/sesame/pose`
- **Image** → Topic: `/sesame/debug_image` *(enable `publish_debug_image:=true`)*

---

## Topics Reference

| Topic | Type | Direction | Description |
|---|---|---|---|
| `/camera/image_raw` | `sensor_msgs/CompressedImage` | ESP32 → host | JPEG frames |
| `/sesame/status` | `std_msgs/String` | ESP32 → host | JSON status blob |
| `/sesame/cmd` | `std_msgs/String` | host → ESP32 | Motion command |
| `/sesame/pose` | `geometry_msgs/PoseStamped` | host → ESP32 | Estimated world pose |
| `/aruco/markers` | `visualization_msgs/MarkerArray` | host | rviz2 visualisation |
| `/sesame/odom_path` | `nav_msgs/Path` | host | Travelled path |
| `/sesame/debug_image` | `sensor_msgs/CompressedImage` | host | Annotated frames |

### Motion commands

| Command | Action |
|---|---|
| `forward` | Walk forward (continuous until changed) |
| `backward` | Walk backward |
| `left` | Turn left |
| `right` | Turn right |
| `rest` | Rest pose (one-shot) |
| `stand` | Stand pose + idle (one-shot) |
| `wave`, `dance`, `swim`, etc. | Animations (one-shot) |
| `stop` | Clear current command |

---

## Architecture Notes

### FreeRTOS Task Layout (ESP32)

| Task | Core | Priority | Responsibility |
|---|---|---|---|
| `camera_task` | 0 | 3 | Grab JPEG frames → shared buffer |
| `ros_spin_task` | 1 | 5 | micro-ROS executor, publish camera + status |
| `movement_task` | 1 | 2 | Execute servo poses, OLED animation |

The ROS spin task has higher priority than the movement task so that incoming
commands and pose updates are processed promptly even during long animations.
Animations yield via `vTaskDelay()` inside `delayWithFace()`, allowing the
spin task to run.

### micro-ROS Reconnection

The firmware implements the standard micro-ROS agent lifecycle:

```
WAITING_AGENT → AGENT_AVAILABLE → AGENT_CONNECTED → AGENT_DISCONNECTED → WAITING_AGENT
```

The robot stops moving and waits for reconnection if the agent disappears.

### Large Message Support (Camera Frames)

The default micro-ROS transport MTU may be too small for full QVGA JPEG
frames. The included `colcon.meta` file at the repo root configures an 8 KB
MTU. To apply it, rebuild the micro-ROS static library:

```bash
pio run -e esp32cam_ros --target clean
pio run -e esp32cam_ros
```

If you still see serialisation errors, reduce the frame size in the firmware:

```cpp
// firmware/sesame-firmware-ros/sesame-firmware-ros.ino
#define CAM_FRAMESIZE  FRAMESIZE_QQVGA   // 160×120 — ~2 KB JPEG
```

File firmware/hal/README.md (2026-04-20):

# Sesame Robot — Hardware Abstraction Layer (HAL)

This folder contains board-specific pin and peripheral configuration headers for the Sesame Robot firmware.  Including `hal/hal.h` from the main sketch pulls in the correct settings for whichever board is selected.

---

## How to select a board

Define a board macro **before** `hal/hal.h` is processed.  The easiest way is to add a `#define` at the very top of `sesame-firmware-main.ino` (above any `#include`):

```cpp
// ── Pick exactly one ──────────────────────────────────────────────────
// #define BOARD_ESP32CAM        // AI-Thinker ESP32-CAM
// #define BOARD_ESP32S3CAM      // Generic ESP32-S3-CAM (placeholder)
// #define BOARD_DISTRO_V2       // Sesame Distro Board V2 (ESP32-S3)
// #define BOARD_DISTRO_V1       // Sesame Distro Board V1 (ESP32-WROOM32)
// (default = Lolin S2 Mini when nothing is defined)
```

Alternatively, pass the flag through your build system (arduino-cli, PlatformIO, etc.):

```
arduino-cli compile --build-property "compiler.cpp.extra_flags=-DBOARD_ESP32CAM" ...
```

---

## Supported boards

### AI-Thinker ESP32-CAM (`BOARD_ESP32CAM`)

**Arduino IDE target:** *AI Thinker ESP32-CAM*

#### I2C bus

GPIO 26 (SIOD) and GPIO 27 (SIOC) are the OV2640 camera SCCB lines.  They are routed only to the camera FFC connector on the PCB and **are not exposed on the external J2/J3 header pins**, so an external device cannot be physically connected to them.

The accessible header GPIO pins on this board are:

| Header | Pins |
|---|---|
| J3 | 5V · GND · IO12 · IO13 · IO15 · IO14 · IO2 · IO4 |
| J2 | 3V3 · GND · IO16 · IO0 · IO3(RX) · IO1(TX) · GND · 5V |

After excluding boot-strapping pins (GPIO 0, 2, 12), serial lines (GPIO 1, 3), the flash-LED pin (GPIO 4), and the PSRAM CS pin (GPIO 16), the only viable I2C candidates are **GPIO 13, 14, and 15**.

Chosen mapping:

| Signal  | GPIO | Rationale |
|---|---|---|
| I2C SDA | **14** | SD_CLK — no boot constraint, physically accessible on J3 |
| I2C SCL | **15** | SD_CMD — internal pull-up keeps it HIGH at boot, matching I2C idle state |

> **Trade-off:** GPIO 14 (SD_CLK) and GPIO 15 (SD_CMD) are consumed by I2C, so the SD card cannot operate simultaneously. The four SD data lines — GPIO 2, 4, 12, and 13 — are preserved. SD support can be re-enabled by switching the board back to a direct-PWM configuration.

#### Servo driver

The camera peripheral occupies all four LEDC timer groups that `ESP32Servo` requires, so direct PWM output is not available on this board.  A **PCA9685** I2C 16-channel PWM driver is used for all eight servo channels instead.

PCA9685 pulse-width tick counts at 50 Hz (4096 ticks = 20 ms period):

| Define | Ticks | Pulse width | Formula |
|---|---|---|---|
| `PCA9685_SERVOMIN` | 150 | ≈ 732 µs  | `150 × 20000 / 4096` µs |
| `PCA9685_SERVOMAX` | 600 | ≈ 2929 µs | `600 × 20000 / 4096` µs |

These match the `732–2929 µs` range used by `ESP32Servo` on legacy boards.

#### SD-card pins

| Signal | GPIO | Status with this HAL |
|---|---|---|
| SD_DATA0  |  2 | Preserved |
| SD_DATA1  |  4 | Preserved |
| SD_DATA2  | 12 | Preserved |
| SD_DATA3  | 13 | Preserved |
| SD_CLK | 14 | **Used as I2C SDA**  |
| SD_CMD | 15 | **Used as I2C SCL**  |

#### Strapping pins (do not reassign)

| GPIO | Function |
|---|---|
|  0 | Boot-mode select (LOW = download mode) |
|  2 | Must be LOW / floating at boot |
| 12 | Must be LOW at boot (PSRAM 1.8 V select) |
| 15 | Must be HIGH at boot (internal pull-up) |

#### Pin summary

| Signal | GPIO | Notes |
|---|---|---|
| I2C SDA |  14  | J3 header — SD_CLK repurposed |
| I2C SCL |  15  | J3 header — SD_CMD repurposed |
| CAM LED | 4  | On-board flash LED (web-toggle capable) |
| PCA9685 addr | 0x40 | Default A0–A5 = LOW |
| Servo driver | PCA9685 channels 0–7 ||

---

### Generic ESP32-S3-CAM (`BOARD_ESP32S3CAM`) — placeholder

**Arduino IDE target:** *ESP32S3 Dev Module* (adjust for your specific module)

> ⚠ **This is a placeholder configuration.**  GPIO assignments vary significantly between ESP32-S3-CAM vendors (FREENOVE, LILYGO T-Camera S3, etc.).  Verify `I2C_SDA` and `I2C_SCL` against your board's schematic before use.

#### I2C bus

Default pins: **GPIO 8 (SDA)** and **GPIO 9 (SCL)** — a common I2C mapping on ESP32-S3 dev-kit layouts.  Update `board_esp32s3cam.h` if your board differs.

#### Servo driver

Same as ESP32-CAM: PCA9685 at address **0x40**.

#### SD-card pins (typical, preserved)

Typical SDMMC wiring on ESP32-S3-CAM modules — verify against your board:

| Signal | GPIO |
|---|---|
| SD_CLK | 39 |
| SD_CMD | 38 |
| SD_D0 | 40 |
| SD_D1 | 41 |
| SD_D2 | 42 |
| SD_D3 | 43 |

---

### Legacy boards (existing behaviour, no PCA9685)

These boards use `ESP32Servo` for direct PWM output.  Their pin settings are kept inline in `hal.h` to preserve the existing firmware behaviour without requiring separate board files.

| Board | Macro | I2C SDA | I2C SCL |
|---|---|---|---|
| Sesame Distro Board V2 | `BOARD_DISTRO_V2` |  8 |  9 |
| Sesame Distro Board V1 | `BOARD_DISTRO_V1` | 21 | 22 |
| Lolin S2 Mini (default)| *(none)* | 33 | 35 |

The `servoPins[]` array for these boards is still defined in the main sketch.

---

## PCA9685 wiring

```
ESP32-CAM (J3 header)   PCA9685 breakout
──────────────────────  ──────────────────────
GPIO 14 (SDA)  ──────►  SDA
GPIO 15 (SCL)  ──────►  SCL
3.3 V  ────────────────  VCC  (logic supply)
GND    ────────────────  GND
                         V+   ← external 5–6 V servo supply
A0–A5  all LOW (default address 0x40)
```

Connect servo signal wires to PCA9685 output channels 0–7, matching the `ServoName` enum (`R1`=0 … `L4`=7).

---

## Required libraries (PCA9685 boards)

Install via the Arduino IDE Library Manager:

- **Adafruit PWM Servo Driver Library** (`Adafruit_PWMServoDriver`)

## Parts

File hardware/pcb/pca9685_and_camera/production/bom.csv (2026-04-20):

Designator | Footprint | Quantity | Value | LCSC Part #
C1, C2, C4 | 0402 | 3 | 4.7uF 6.3v (10%)
C10, C12, C3, C5, C6, C8 | 0402 | 6 | 0.1uF 10v (10%)
C11, C13, C7, C9 | 0603 | 4 | 10uF 16v (10%)
C14, C21, C22, C24, C25, C40, C42 | 0603 | 7 | 10 uF 10V
C15, C16, C23, C26, C41, C43, C49 | 0402 | 7 | 100nF 10V
C17 | 0603 | 1 | 2.2 uF 10V
C18 | 0402 | 1 | 82pF 10V
C19 | 0402 | 1 | 39 pF 10V
C20 | 1206 | 1 | 47 uF 10V
C27 | 0603 | 1 | 22pF 10V
C28, C29, C30, C31, C32, C33, C34, C35, C36, C37, C38, C39, C46, C47, C48 | 1206 | 15 | 47uf
C44, C45 | 0603 | 2 | 1 uF 10V
D1 | SOT23-6 | 1 | DT1042-04SO
D2 | D_SMA | 1 | SS24
D3, D4, D5 | 0603 | 3 | LED
FL1 | L_CommonModeChoke_Coilcraft_0603USB | 1 | 0603USB-142
J1 | FPC_1x24_P0.5mm_Horizontal_DualContact | 1 | camera
J10, J13, J17, J4, J7 | PinHeader_1x03_P2.54mm_Vertical | 5 | A
J11, J14, J18, J5, J8 | PinHeader_1x03_P2.54mm_Vertical | 5 | B
J12, J15, J19, J6, J9 | PinHeader_1x03_P2.54mm_Vertical | 5 | C
J16 | JST_PH_B2B-PH-K_1x02_P2.00mm_Vertical | 1 | BATT
J2 | USB-C_16 | 1 | USB_C_Receptacle
J20 | PinHeader_1x04_P2.54mm_Vertical | 1 | Conn_01x04_Pin
J3 | PinHeader_1x03_P2.00mm_Vertical | 1 | CAM_REGS_EN 1_2
L1 | L_TDK_VLS6045EX_VLS6045AF | 1 | 2.2 uH
L2 | 1206 | 1 | 2.2 uH 3A
Q1 | SOT-23 | 1 | AO3401A
R1, R30, R33, R5 | 0603 | 4 | 10k
R2, R3, R4 | 0402 | 3 | 0R
R23, R24 | 0402 | 2 | 5k1
R25, R26 | 0603 | 2 | 100k
R27 | 0603 | 1 | 48K7
R28 | 0603 | 1 | 442K
R29 | 0603 | 1 | 28K7
R31 | 0603 | 1 | 680kk
R32 | 0603 | 1 | 150
R34, R35 | 0603 | 2 | 4k7
R36, R37, R38 | 0402 | 3 | 470
R39 | 0603 | 1 | 1k
R40 | 0402 | 1 | 1k54
R41 | 0402 | 1 | 69k8
SW1 | SW_SPST_EVQP2_MiddlePushTravel_H2.5mm | 1 | RESET
SW2 | SW_SPST_EVQP2_MiddlePushTravel_H2.5mm | 1 | BOOT
TH1 | R_Axial_DIN0204_L3.6mm_D1.6mm_P2.54mm_Vertical | 1 | 10k 3892
U1 | ESP32-S3-WROOM-1U | 1 | ESP32-S3-WROOM-1
U2 | SOT-23-5 | 1 | ME6211C28M5
U3 | SOT-23-5 | 1 | ME6211C15M5
U4 | RQQ0011A-MFG | 1 | PTPS61288RQQR
U5 | SOT23-5 | 1 | AP3429 / SY8088AAC
U6 | QFN-28-1EP_6x6mm_P0.65mm_EP4.25x4.25mm | 1 | PCA9685BS
U8 | MSOP-10_3x3mm_P0.5mm | 1 | MCP73833-xxx-UN

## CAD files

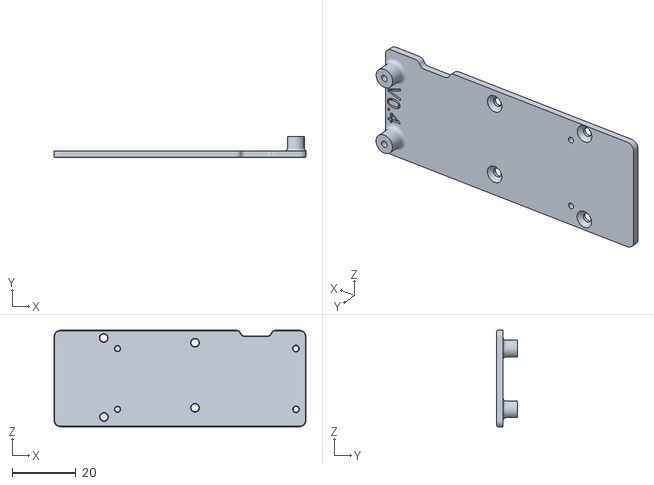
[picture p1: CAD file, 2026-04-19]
hardware/cad/stl/main_carrier.stl
79.0 x 6.43 x 30.3

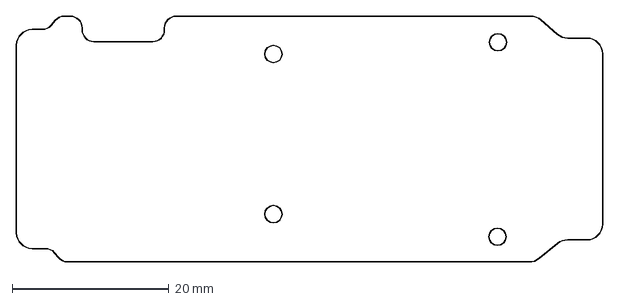
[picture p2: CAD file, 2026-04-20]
hardware/cad/sesame-pcbSketch.dxf
74.7 x 31.3 mm

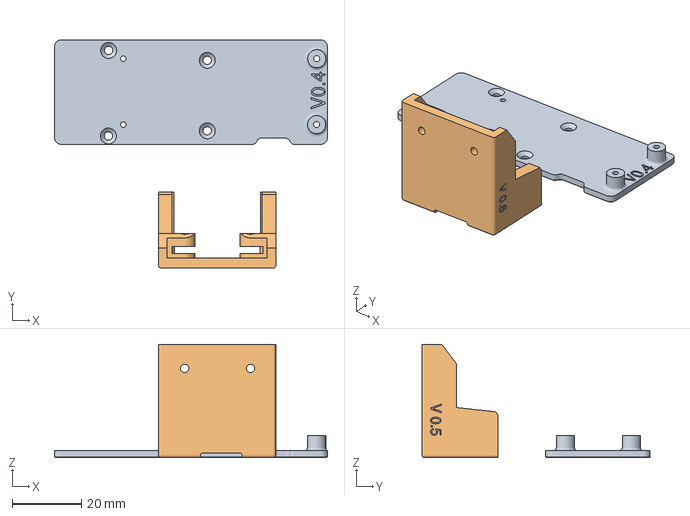
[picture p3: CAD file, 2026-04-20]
hardware/cad/stl/carriers.3mf
79.0 x 66.1 x 32.8 mm
main_carrier.stl
esp_carrier.stl

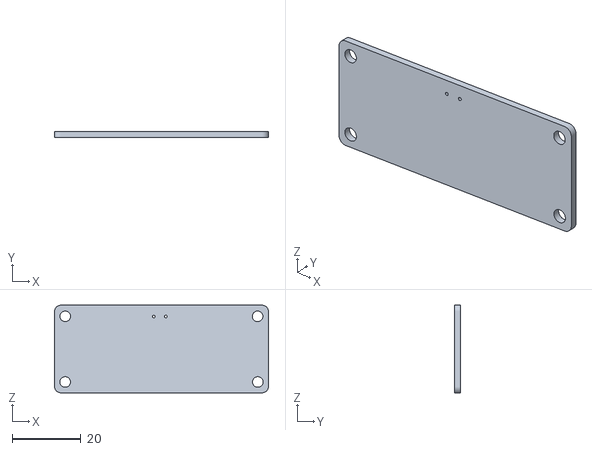
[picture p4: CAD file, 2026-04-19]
hardware/cad/stl/pca9685.stl
62.2 x 1.60 x 25.5

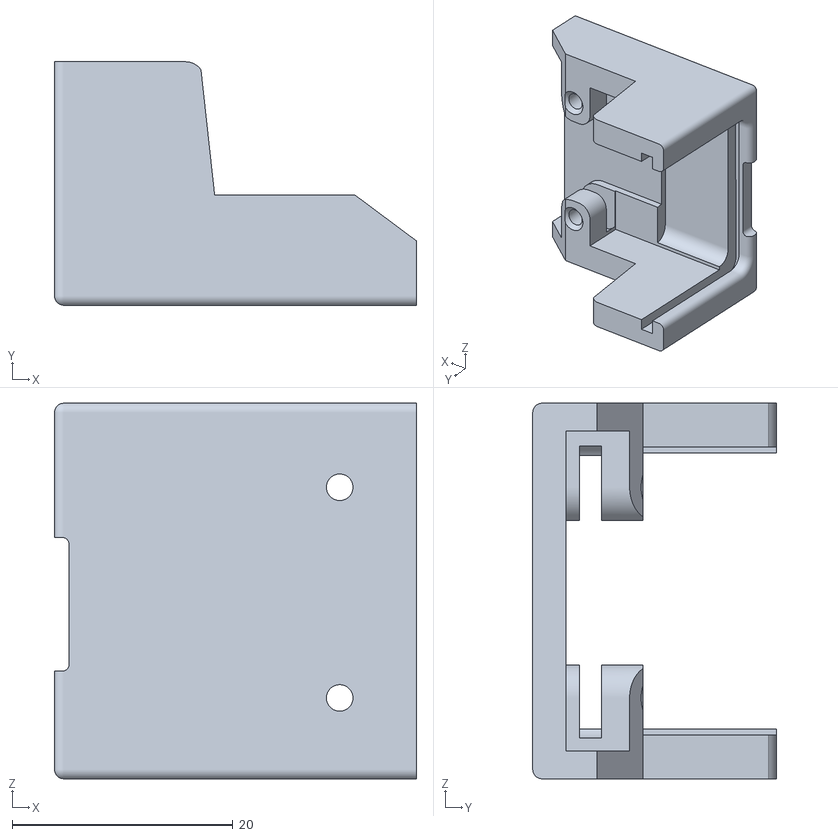
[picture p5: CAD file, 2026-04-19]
hardware/cad/stl/esp_carrier.stl
32.8 x 22.0 x 34.0

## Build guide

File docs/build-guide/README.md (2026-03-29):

# Build Guide
Complete build guide for the Sesame Robot.

Use this walkthrough alongside the BOM, wiring guide, and printing notes to stay organized. The table below previews each phase, its goal, and the doc to reference if you get stuck.

| Phase | Goal | Est. Time | Key References |
| --- | --- | --- | --- |
| 1. Gather parts | Print plastics and source electronics | 1–2 sessions | [hardware/bom](../../hardware/bom/README.md), [hardware/printing](../../hardware/printing/README.md) |
| 2. Electronics & wiring | Build ~90% of the harness | 1 session | [docs/wiring-guide](../wiring-guide/README.md) |
| 3. Hardware pre-assembly | Prep joints, feet, top cover | 1 session | This guide (Phase 3) |
| 4. Hardware main assembly | Mount motors + electronics | 1–2 sessions | This guide (Phase 4) |
| 5. Calibrate & finish | Flash tester, align joints, close up | 1 session | Firmware README + remaining sections |

> [!TIP]
> Treat each phase like a milestone. Snap progress photos and mark issues before moving on so troubleshooting later is painless.

<p align="center">
  <a href="https://www.youtube.com/watch?v=NIgoQVQF_Ng">
    tutorial-button
  </a>
</p>

## Phase 1: Gathering all the parts.

**Goal:** Print the full shell set and collect every electronic, connector, and fastener before any soldering starts.

**You’ll need:**
- [hardware/bom](../../hardware/bom/README.md) for electronics, power gear, and Amazon search links.
- [hardware/printing](../../hardware/printing/README.md) for STL names, orientations, and support notes.

There are 11 printed parts (internal frame, top/bottom covers, joints R1–R4/L1–L4) plus 6–8 main electronic components depending on the wiring approach.

Here's what a complete set looks like:

all-hardware

**Phase 1 checklist**
- [ ] All plastic parts printed, and cleaned up.
- [ ] MG90 servos tested quickly on a servo tester or Arduino to catch DOA units.
- [ ] Power plan decided (USB-C PD vs. battery + buck) and matching connectors sourced (2× 10440 Li-ion cells in a 2× AAA holder fit the stock battery cavity).
- [ ] Consumables stocked: solder, flux, heat-shrink, zip ties, M2 hardware.

## Phase 2: Electronics and Wiring

**Goal:** Build 90% of the harness on the bench so the frame install is quick.

1. Open the [wiring guide](../wiring-guide/README.md) and pick the section that matches your build (S2 Mini hand-wired, Distro Board V2, or Distro Board V1 legacy).
2. Lay out every connector in the order shown on the wiring diagram before soldering; this keeps the data lines from getting crossed.
3. Tin and solder the rails/buck converter first, then route signal wires. Leave generous length for the motors that terminate near the hips.
4. This is optional but you can also label each servo lead (S0–S7) using tape flags as soon as it is soldered. Future you will thank you.

> [!WARNING]
> Stop before permanently wiring the power switch or OLED. Those final joints happen after the electronics are seated in the frame so you can dial the cable length exactly.

**Phase 2 checklist**
- [ ] Harness built per your wiring diagram with all joints strain-relieved.
- [ ] Buck converter trimmed to 5.1 V output and shrink-wrapped.
- [ ] Servo leads labeled and loosely bundled by destination.
- [ ] Power switch and OLED leads pre-cut but still un-soldered.

## Phase 3: Hardware Pre-Assembly

### Hip Joints

**Goal:** Pre-load the four hip joints (R1, R2, L1, L2) with one-sided servo horns so installation is tool-free later.

1. Lay out the four hip joint parts. Find the one-sided servo horns from the servo motor bags (ignore the included extra screws).
2. Notice the servo horn has a taller side and a shorter side. Press the shorter side into the hip joint. There should be just enough clearance to press this piece in flush.
3. While holding the horn flat, drive an M2 × 5 mm self-threading screw (the ones with a larger gap between thread spikes) through the second hole in the horn and into the plastic until secure.

install-horn

> [!TIP]
> Do not over-tighten self-threading screws. Since the threads are plastic, over-tightening will permanently damage the hole.

Repeat for all four hip joints:

hip-joints

> [!IMPORTANT]
> Do **not** mount these joints on the servos yet. Calibration requires every motor shaft to spin freely.

dont-mount

### Leg Joints

Slide each leg shell over its dedicated motor before the frame install. Use the built-in gap to route wires without pinching them.

servo-install-leg

- Feed the motor wires through the side slot.
- Push the motor into the side of the leg piece that has holes in it. Make sure the motor shaft is at the very top.
- Confirm the motor sits flush and use self-threading screws to permanently affix the motors into the leg pieces.

Repeat for the remaining legs.

leg-joints

### Top Cover & Soldering

The next step is loading the OLED and power switch into the top cover. At this stage, we also do the minimal soldering required for the build.

1. **Power Switch:** Press the battery switch firmly into the back slot of the top cover. DO NOT connect the wires yet.

insert-rocker-switch

2. **OLED Display:** Apply a small amount of solder to the pin headers on the display (tinning). Using the pre-crimped JST connector wires, match the wires to their respective marks on the display and solder them. 

display-soldering

3. **Battery Connectors (Main Board):** Remove sheathing on the ends of the battery connector wires, tin them, and solder them to the battery pads on the main board in an L-shape pointing upwards. Make sure they do not go over the edge of the board, or the top cover won't fit.

battery-connector-solder

4. **Install Display:** Push the wired OLED display gently into its slot inside the top cover. Insert self-threading screws into the small screw holes beside the display to clamp it permanently in place.

securing-display

**Phase 3 checklist**
- [ ] Hip joints pre-loaded with servo horns, not yet attached to motors.
- [ ] Leg pieces installed on every motor.
- [ ] Power switch and OLED display installed in the top cover.
- [ ] Battery connectors soldered to the main board.

## Phase 4: Hardware Main Assembly

**Goal:** Seat the frame motors, route wiring, and secure the electronics stack so the robot is ready for calibration.

1. **Battery Holder:** Insert the battery holder into the back of the internal frame piece. Route the red and black wires up the slot.
2. **Motor Installation:** While holding the battery wires in place, insert the four remaining side motors. The motor shaft should be facing towards the outside of the internal frame.
  - Insert motors at an angle and press them the rest of the way. Make sure not to pinch any wires at the bottom.
3. **Secure Motors:** Use self-threading screws to permanently affix all four side motors to the frame.

insert-motors

rotate-motor

Make sure the motor shafts are closest to the outer edge of the frame. 

complete-motors

## Installing the Main Electronics

Before dropping hardware in, trim or bundle any stray wires so nothing can flop into the servo gears and double-check that every connection exits upward.

1. Pre-route any long wires upward so they naturally hug the future top cover.
2. Lower the electronics harness into the cavity while keeping the USB port toward the rear.
3. **S2 Mini build:** Screw the controller (and optional protoboard) directly into the frame using the provided mounting holes. If you built a small protoboard backplane, use the spare holes in the internal frame to secure it so the servo plugs are easy to reach later.

s2-secure-electronics

4. **Distro Board V1 build (Legacy):** Install four M2.5 × 5 mm male-female standoffs to raise the Sesame Distro Board V1 so it clears the ESP32 DevKit. Then secure the assembly using the top screws.

secure-distro-board

5. **Distro Board V2 build (Build Kits):** Mount by gently bringing cables towards the center nicely so that the main board can sit properly. Attach the main board to the internal frame. It has two mounting holes in the corner that you attach using self-threading screws.

secure-distro-boardv2

> [!TIP]
> Notch = front. USB port = back. Use these two cues any time the orientation feels ambiguous.

## Calibrating & Running the Testing Firmware

**Goal:** Teach the controller where each motor sits so the walking poses land correctly.

> [!CAUTION]
> Never run calibration with joints attached. A misaligned horn can stall or strip a servo instantly. All motor shafts should be free spinning at this point.

**For S2 Mini and Distro Board V1 (Legacy) Builds:**
1. Inspect the harness to ensure no bare conductors can short during testing. Add heat-shrink or tape where needed.
2. Connect a reliable USB-C cable and flash `sesame-motor-tester.ino` from the [debugging-firmware](../../firmware/debugging-firmware/) folder using Arduino IDE. If you have never flashed an ESP32 before, pause here and follow a quick tutorial so you are comfortable resetting/entering boot mode.
3. Open the serial monitor. You should see the tester menu.
4. Command all motors to 90°. Starting from Motor 0, plug its connector into the appropriate header. The servo should immediately whirr into the 90° position. Repeat for Motors 1–7. Skip to Step 4 below.

**For Distro Board V2 (Build Kits):**
If you are using the V2 Board from a Build Kit, it comes **pre-flashed** with the Sesame firmware! There is no need to plug into a computer and use Arduino IDE to flash firmware. 

1. **Power Up:** Plug the board into a strong USB power supply (fast chargers for phones or laptop chargers work great). Note: If you are using the V2 Distro board, it currently has instabilities with the battery system and won't work on batteries, you must plug via USB-C (A V3 Distro board fix will be sent). 
2. **Connect to Portal:** Check the Wi-Fi networks on your phone or computer. The Sesame board will create an access point. Connect to it to open the controller portal. (If on desktop and the portal doesn't show, go to `sesame-root.local` in your browser. Mobile is recommended.)
3. **Initialize PWM:** Tap the "Standby" button in the portal to initialize the PWM channels. The moment you plug a motor in, it will go to its correct active position.

**General instructions continuing:**

4. **Refer to Diagram:** Use the diagram below to associate motor numbers with their physical position. Ensure the frames are roughly oriented correctly.

angle-guide

5. **Plug Motors In:** Starting with Motor 0, plug the connector into the corresponding board header. 
   - **Crucial:** Ensure the brown wire aligns with the ground rail! Upon plugging it in, you should hear it whir into life and hold position. 
   - Repeat for all 8 motors. 

> [!TIP]
> 99% of the time, if your motor is moving in the wrong direction, crashing, or being sporadic, the motor is plugged into the wrong slot. Check your wiring!

## Attaching Hip & Leg Joints

Now we attach the joints while the motors are turned on and holding their "Stand" position.

1. **Hip Joints:** Select the matching hip joint for your motor. While in "Stand" mode, push the hip joint onto the motor shaft at a 45-degree angle. 
2. **Test Angles:** Tap "Rest" in the portal. The hip joint should move perfectly parallel to the body. Tap "Stand" again, and it should go back to 45°. Alternate this to ensure it's placed correctly.
3. **Fasten Hip:** If it looks good, fasten the hip joint to the motor using an M2.5 machine screw through the main hole into the motor shaft. Gently tighten (don't over-torque against the motor as this may cause a brownout).
4. **Legs:** Repeat the same process with the leg joints. Check against "Rest" and "Stand", ensure nothing collides, and then affix using screws.

reference-configuration

## Final Wiring and Top Cover

Now to clean up the robot and secure everything. 

1. **Battery Connections:** Insert the battery wires into the screw terminal on the board and use a flathead screwdriver to tighten them securely.
2. **Wire Routing:** Flip the robot over. There are channels for all the wires on the underside. Securely press all of the wires into these channels.
3. **Bundling:** Separate the wires gently into two groups (left and right). Wrap a zip tie around each bundle, fold it once, and tighten the zip tie to create a tight bundle. This helps the top cover fit seamlessly. 

wire-routing

zip-tie-bundles

4. **Testing the Switch:** Make sure the batteries are charged and insert them. Flip the switch and check if the Wi-Fi network appears or if the display lights up. If things aren't working, double-check connections.

> [!NOTE]
> **V2 Board Owners:** If you are using the V2 Distro board from a kit, there are instabilities with the battery system that prevent reliable battery usage. You must run your Sesame via USB-C (fast charger / laptop charger) for now. A free V3 Distro board will be provided to pre-order kit buyers!

5. **Top Cover:** Gently pack all the bundles in and slowly press the top cover down onto the electronic components. Be very gentle to avoid shorting or disconnecting anything.
6. **Securing Top Cover:** Hold the whole robot together and insert the M2 self-threading screws into the bottom of the frame where they thread securely into the mounting holes for the top cover.

secure-top-cover

## Bottom Cover & Final Checks

insert-battery

1. Set the bottom cover in place, checking that no wires are trapped. Use the remaining two self-threading screws into the bottom to secure it. 

screw-on-bottom-cover

2. You can apply the included sticky pads to the feet if you like!

**Phase 4 checklist**
- [ ] Motors mounted and screwed in on hip and leg joints.
- [ ] Harness routed into channels, zip-tied without pinch points.
- [ ] Top and bottom covers installed.

> [!TIP]
> A common issue on battery power (if you upgrade) is that your Sesame robot will crash on movement. Setting the motor current delay higher in the settings may help, but upgrading to a Lithium Polymer (LiPo) cell often solves it for advanced users! 

Great job! The hardware is complete.

sesame-done

## Final Checks and Flashing the Firmware

Now we just need to do a few checks to make sure everything is working and we can flash the firmware onto the microcontroller.

**Sanity checks**
1. Toggle the power switch (if you installed a battery) and confirm it fully disconnects the pack.
2. Confirm the USB-C port is accessible for future firmware updates.
3. Inspect the OLED wiring one last time to ensure SDA/SCL aren’t swapped.

**Flash production firmware (For DIY / S2 Mini / Distro V1)**
If you are using the V2 Build kit board, you can skip this step! It is pre-flashed.
1. Choose the code variant from the firmware folder. Customize pin definitions if you're using a different ESP32.
2. Use Arduino IDE to flash the full firmware bundle (motors + faces). Detailed notes live in [firmware/README.md](../../firmware/README.md).
3. Connect to Sesame’s Wi-Fi AP, load the control page, and trigger a pose to verify everything moves as expected.

That’s it. You’ve built Sesame! From here you can design new poses in [Sesame Studio](../../software/sesame-studio/README.md) or tweak the hardware per [hardware/README.md](../../hardware/README.md), or whatever you want!

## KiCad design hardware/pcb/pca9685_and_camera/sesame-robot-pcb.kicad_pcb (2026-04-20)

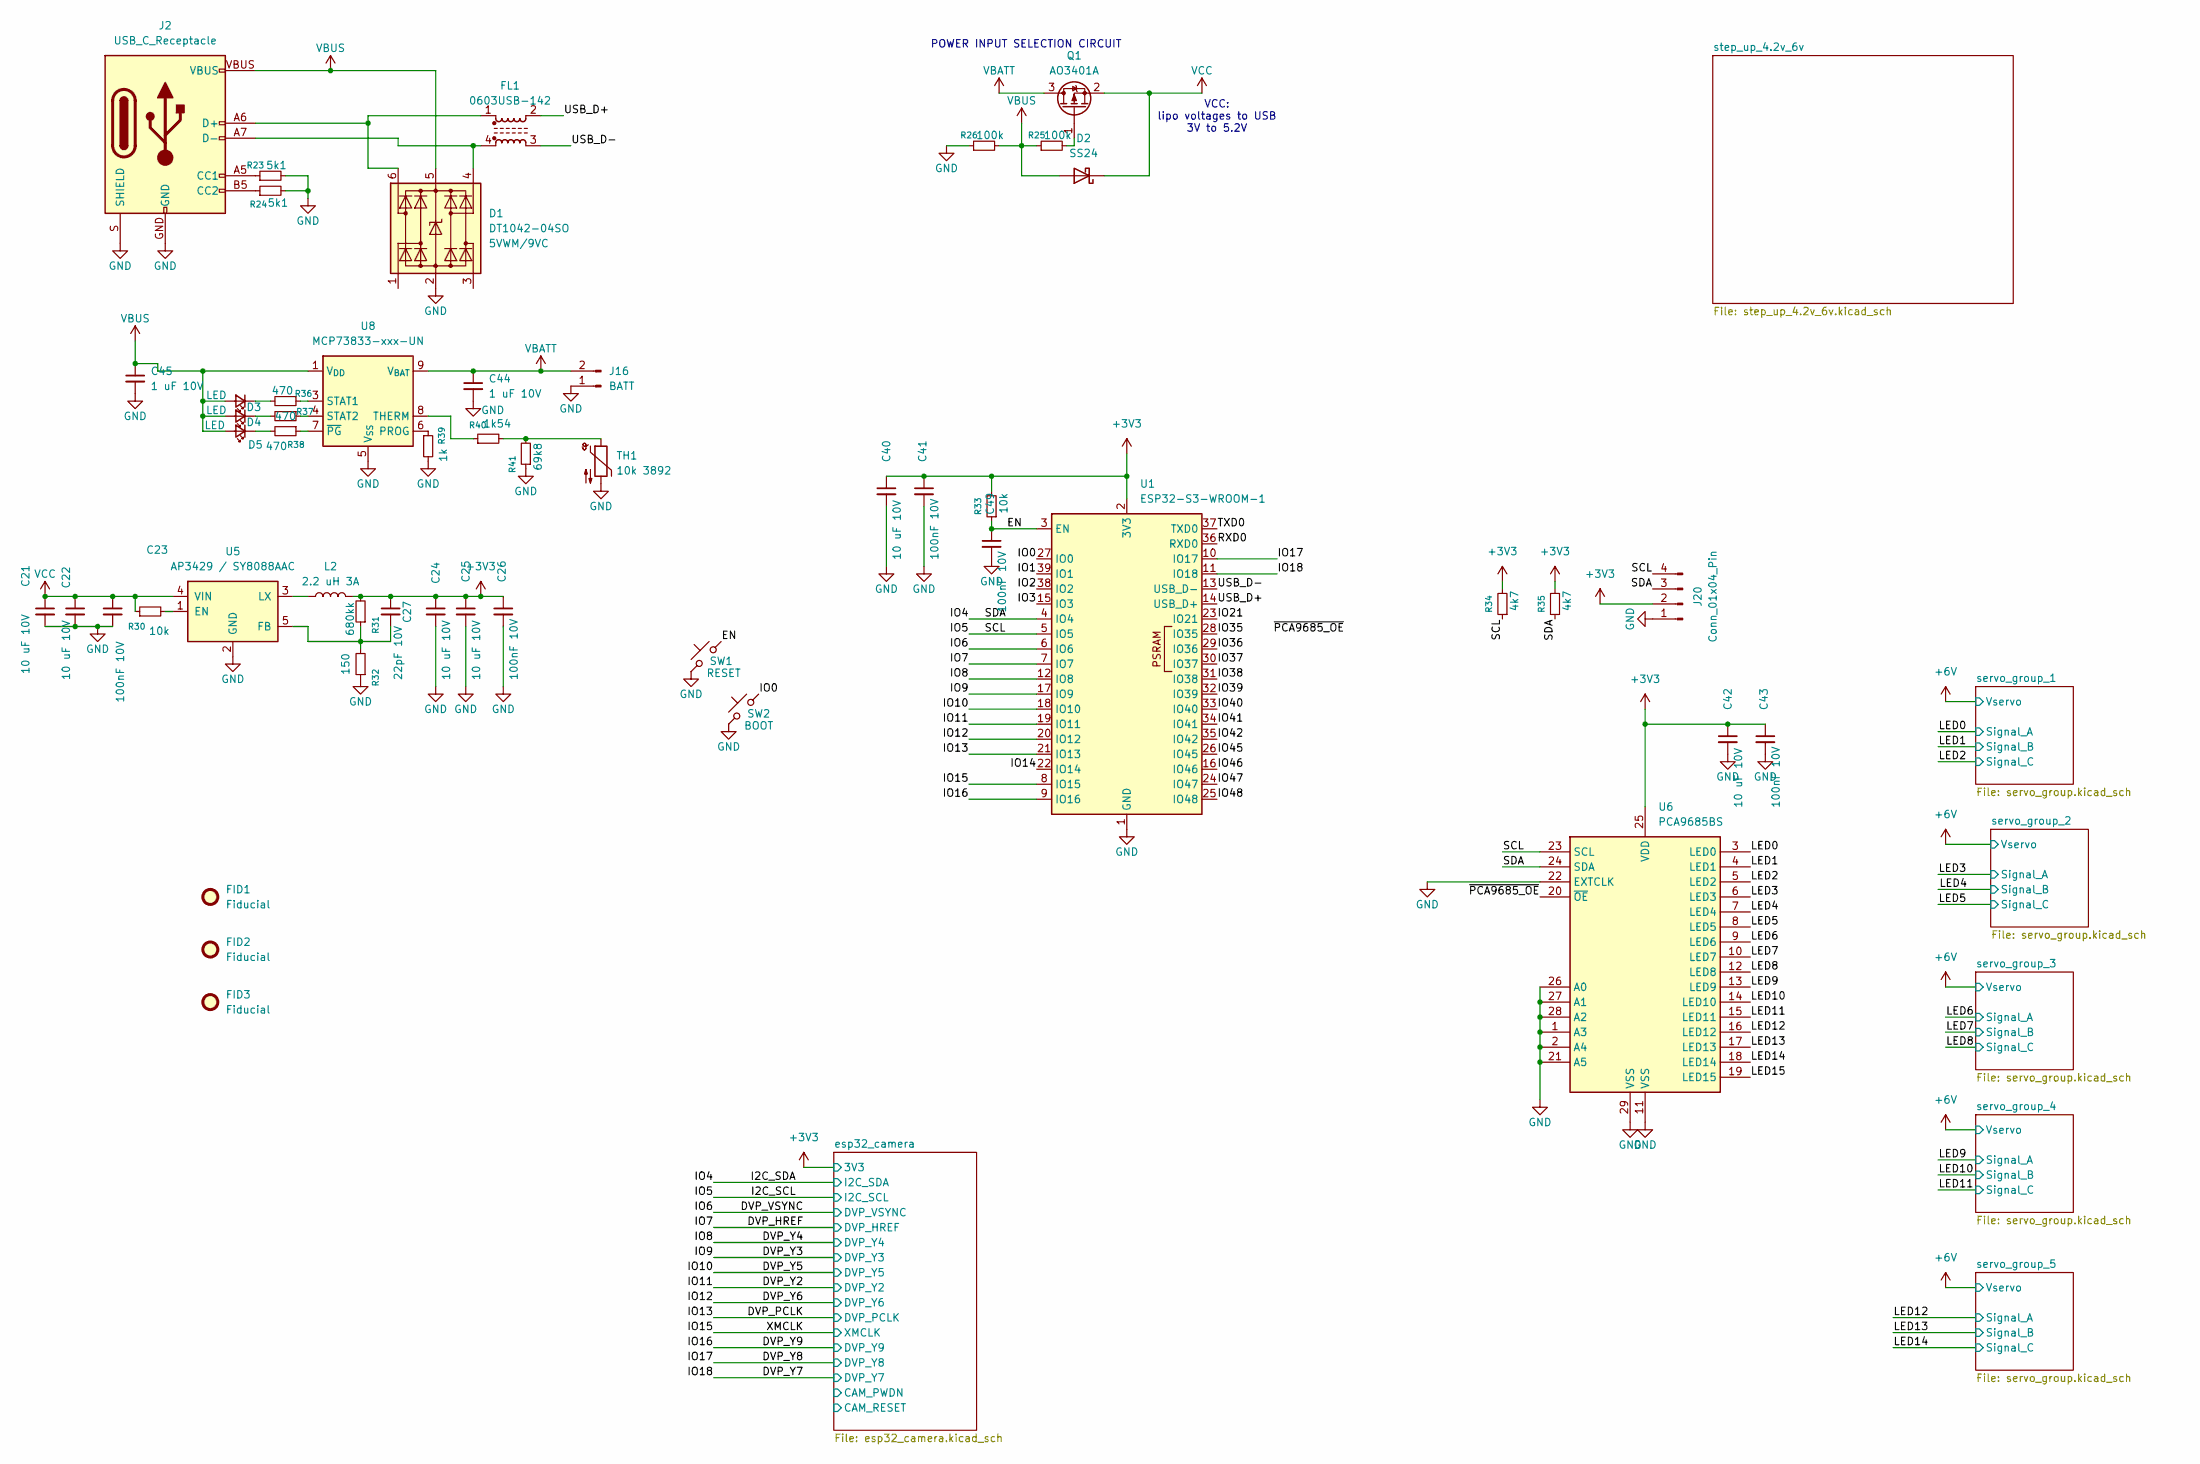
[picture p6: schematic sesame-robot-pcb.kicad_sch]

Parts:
C21, C22, C24, C25, C40, C42: 10 uF 10V; C_0603_1608Metric
C23, C26, C41, C43, C49: 100nF 10V; C_0402_1005Metric
C27: 22pF 10V; C_0402_1005Metric
C44, C45: 1 uF 10V; C_0603_1608Metric
D1: DT1042-04SO; SOT23-6; Rating 5VWM/9VC
D2: SS24; D_SMA
D3, D4, D5: LED; LED_0603_1608Metric
FID1, FID2, FID3: Fiducial; Fiducial_0.5mm_Mask1.5mm
FL1: 0603USB-142; L_CommonModeChoke_Coilcraft_0603USB
J2: USB_C_Receptacle; USB-C_16
J16: BATT; JST_PH_B2B-PH-K_1x02_P2.00mm_Vertical
J20: Conn_01x04_Pin; PinHeader_1x04_P2.54mm_Vertical
L2: 2.2 uH 3A; L_1206_3216Metric
Q1: AO3401A; SOT-23
R23, R24: 5k1; R_0402_1005Metric
R25, R26: 100k; R_0603_1608Metric
R30, R33: 10k; R_0603_1608Metric
R31: 680kk; R_0603_1608Metric
R32: 150; R_0603_1608Metric
R34, R35: 4k7; R_0603_1608Metric
R36, R37, R38: 470; R_0402_1005Metric
R39: 1k; R_0603_1608Metric
R40: 1k54; R_0402_1005Metric
R41: 69k8; R_0402_1005Metric
SW1: RESET; SW_SPST_EVQP2_MiddlePushTravel_H2.5mm
SW2: BOOT; SW_SPST_EVQP2_MiddlePushTravel_H2.5mm
TH1: 10k 3892; R_Axial_DIN0204_L3.6mm_D1.6mm_P2.54mm_Vertical
U1: ESP32-S3-WROOM-1; ESP32-S3-WROOM-1U
U5: AP3429 / SY8088AAC; SOT23-5
U6: PCA9685BS; QFN-28-1EP_6x6mm_P0.65mm_EP4.25x4.25mm
U8: MCP73833-xxx-UN; MSOP-10_3x3mm_P0.5mm

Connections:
+3V3: C24.1, C25.1, C26.1, C27.1, C40.1, C41.1, C42.1, C43.1, J20.2, L2.2, R31.2, R33.2, R34.2, R35.2, U1.2 (3V3), U6.25 (VDD); also elsewhere on the board
/DVP_HREF: U1.7 (IO7); also elsewhere on the board
/DVP_PCLK: U1.21 (IO13); also elsewhere on the board
/DVP_VSYNC: U1.6 (IO6); also elsewhere on the board
/DVP_Y2: U1.19 (IO11); also elsewhere on the board
/DVP_Y3: U1.17 (IO9); also elsewhere on the board
/DVP_Y4: U1.12 (IO8); also elsewhere on the board
/DVP_Y5: U1.18 (IO10); also elsewhere on the board
/DVP_Y6: U1.20 (IO12); also elsewhere on the board
/DVP_Y7: U1.11 (IO18); also elsewhere on the board
/DVP_Y8: U1.10 (IO17); also elsewhere on the board
/DVP_Y9: U1.9 (IO16); also elsewhere on the board
/EN: C49.1, R33.1, SW1.2, U1.3 (EN)
/I2C_SCL: J20.4, R34.1, U1.5 (IO5), U6.23 (SCL); also elsewhere on the board
/I2C_SDA: J20.3, R35.1, U1.4 (IO4), U6.24 (SDA); also elsewhere on the board
/IO0: SW2.2, U1.27 (IO0)
/IO1: U1.39 (IO1)
/IO2: U1.38 (IO2)
/IO3: U1.15 (IO3)
/IO14: U1.22 (IO14)
/IO15: U1.8 (IO15); also elsewhere on the board
/IO21: U1.23 (IO21)
/IO35: U1.28 (IO35)
/IO36: U1.29 (IO36)
/IO37: U1.30 (IO37)
/IO38: U1.31 (IO38)
/IO39: U1.32 (IO39)
/IO40: U1.33 (IO40)
/IO41: U1.34 (IO41)
/IO42: U1.35 (IO42)
/IO45: U1.26 (IO45)
/IO46: U1.16 (IO46)
/IO47: U1.24 (IO47)
/IO48: U1.25 (IO48)
/LED0: U6.3 (LED0); also elsewhere on the board
/LED1: U6.4 (LED1); also elsewhere on the board
/LED2: U6.5 (LED2); also elsewhere on the board
/LED3: U6.6 (LED3); also elsewhere on the board
/LED4: U6.7 (LED4); also elsewhere on the board
/LED5: U6.8 (LED5); also elsewhere on the board
/LED6: U6.9 (LED6); also elsewhere on the board
/LED7: U6.10 (LED7); also elsewhere on the board
/LED8: U6.12 (LED8); also elsewhere on the board
/LED9: U6.13 (LED9); also elsewhere on the board
/LED10: U6.14 (LED10); also elsewhere on the board
/LED11: U6.15 (LED11); also elsewhere on the board
/LED12: U6.16 (LED12); also elsewhere on the board
/LED13: U6.17 (LED13); also elsewhere on the board
/LED14: U6.18 (LED14); also elsewhere on the board
/LED15: U6.19 (LED15)
/RXD0: U1.36 (RXD0)
/TXD0: U1.37 (TXD0)
/USB_D+: FL1.2, U1.14 (USB_D+)
/USB_D-: FL1.3, U1.13 (USB_D-)
/~PCA9685_OE: U6.20 (~OE)
GND: C21.2, C22.2, C23.2, C24.2, C25.2, C26.2, C40.2, C41.2, C42.2, C43.2, C44.2, C45.2, C49.2, D1.2 (GND), J2.GND, J2.S (SHIELD), J16.1, J20.1, R23.2, R24.2, R26.1, R32.1, R39.2, R41.1, SW1.1, SW2.1, TH1.2, U1.1 (GND), U1.40 (GND), U1.41 (GND), U5.2 (GND), U6.1 (A3), U6.2 (A4), U6.11 (VSS), U6.21 (A5), U6.22 (EXTCLK), U6.26 (A0), U6.27 (A1), U6.28 (A2), U6.29 (VSS), U8.5 (V_{SS}); also elsewhere on the board
unnamed: D1.4 (I/O3), FL1.4, J2.A7 (D-), J2.B7 (D-)
unnamed: D1.6 (I/O4), FL1.1, J2.A6 (D+), J2.B6 (D+)
unnamed: D3.1 (K), R36.2
unnamed: D4.1 (K), R37.2
unnamed: D5.1 (K), R38.2
unnamed: J2.A5 (CC1), R23.1
unnamed: J2.B5 (CC2), R24.1
unnamed: Q1.1 (G), R25.2
unnamed: R40.2, R41.2, TH1.1
unnamed: R30.2, U5.1 (EN)
unnamed: C27.2, R31.1, R32.2, U5.5 (FB)
unnamed: L2.1, U5.3 (LX)
unnamed: R39.1, U8.6 (PROG)
unnamed: R36.1, U8.3 (STAT1)
unnamed: R37.1, U8.4 (STAT2)
unnamed: R40.1, U8.8 (THERM)
unnamed: R38.1, U8.7 (~PG)
VBATT: C44.1, J16.2, Q1.3 (D), U8.9 (V_{BAT}), U8.10 (V_{BAT})
VBUS: C45.1, D1.5 (VCC), D2.2 (A), D3.2 (A), D4.2 (A), D5.2 (A), J2.VBUS, R25.1, R26.2, U8.1 (V_{DD}), U8.2 (V_{DD})
VCC: C21.1, C22.1, C23.1, D2.1 (K), Q1.2 (S), R30.1, U5.4 (VIN); also elsewhere on the board

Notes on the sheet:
VCC: lipo voltages to USB 3V to 5.2V
POWER INPUT SELECTION CIRCUIT

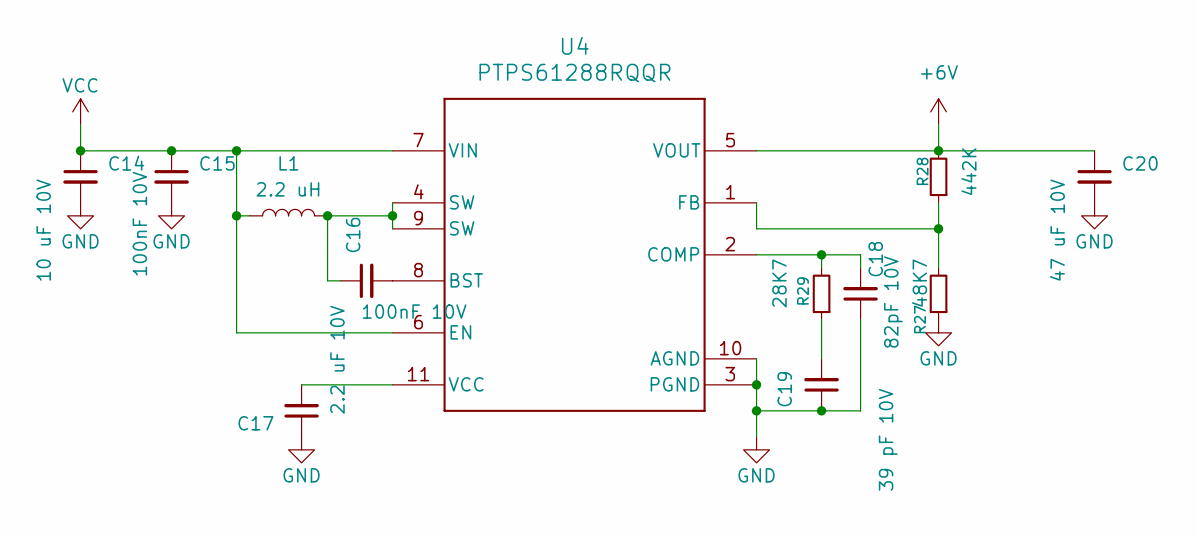
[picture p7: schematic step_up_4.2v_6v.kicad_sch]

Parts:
C14: 10 uF 10V; C_0603_1608Metric
C15, C16: 100nF 10V; C_0402_1005Metric
C17: 2.2 uF 10V; C_0603_1608Metric
C18: 82pF 10V; C_0402_1005Metric
C19: 39 pF 10V; C_0402_1005Metric
C20: 47 uF 10V; C_1206_3216Metric
L1: 2.2 uH; L_TDK_VLS6045EX_VLS6045AF; mpn# SRP5030HMT-1R0M
R27: 48K7; R_0603_1608Metric
R28: 442K; R_0603_1608Metric
R29: 28K7; R_0603_1608Metric
U4: PTPS61288RQQR; RQQ0011A-MFG

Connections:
+6V: C20.1, R28.2, U4.5 (VOUT); also elsewhere on the board
GND: C14.2, C15.2, C17.1, C18.1, C19.1, C20.2, R27.1, U4.3 (PGND), U4.10 (AGND); also elsewhere on the board
unnamed: C16.1, L1.2, U4.4 (SW), U4.9 (SW)
unnamed: C19.2, R29.1
unnamed: C16.2, U4.8 (BST)
unnamed: C18.2, R29.2, U4.2 (COMP)
unnamed: R27.2, R28.1, U4.1 (FB)
unnamed: C17.2, U4.11 (VCC)
VCC: C14.1, C15.1, L1.1, U4.6 (EN), U4.7 (VIN); also elsewhere on the board

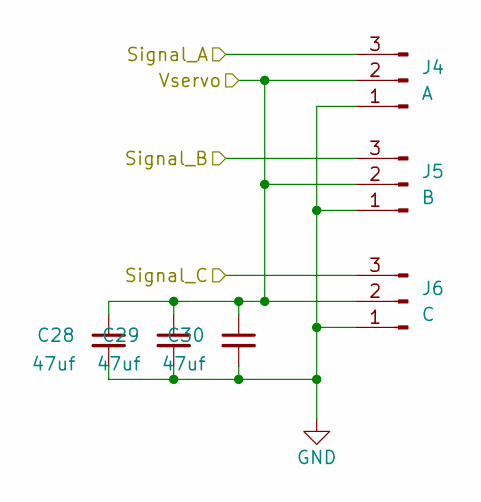
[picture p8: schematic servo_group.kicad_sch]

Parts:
C28, C29, C30: 47uf; C_1206_3216Metric
J4: A; PinHeader_1x03_P2.54mm_Vertical
J5: B; PinHeader_1x03_P2.54mm_Vertical
J6: C; PinHeader_1x03_P2.54mm_Vertical

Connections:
+6V: C28.1, C29.1, C30.1, J4.2, J5.2, J6.2; also elsewhere on the board
/LED0: J4.3; also elsewhere on the board
/LED1: J5.3; also elsewhere on the board
/LED2: J6.3; also elsewhere on the board
GND: C28.2, C29.2, C30.2, J4.1, J5.1, J6.1; also elsewhere on the board

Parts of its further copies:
C31, C32, C33, C34, C35, C36, C37, C38, C39, C46, C47, C48: 47uf; C_1206_3216Metric
J7, J10, J13, J17: A; PinHeader_1x03_P2.54mm_Vertical
J8, J11, J14, J18: B; PinHeader_1x03_P2.54mm_Vertical
J9, J12, J15, J19: C; PinHeader_1x03_P2.54mm_Vertical

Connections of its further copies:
+6V: C31.1, C32.1, C33.1, C34.1, C35.1, C36.1, C37.1, C38.1, C39.1, C46.1, C47.1, C48.1, J7.2, J8.2, J9.2, J10.2, J11.2, J12.2, J13.2, J14.2, J15.2, J17.2, J18.2, J19.2; also elsewhere on the board
/LED3: J7.3; also elsewhere on the board
/LED4: J8.3; also elsewhere on the board
/LED5: J9.3; also elsewhere on the board
/LED6: J10.3; also elsewhere on the board
/LED7: J11.3; also elsewhere on the board
/LED8: J12.3; also elsewhere on the board
/LED9: J13.3; also elsewhere on the board
/LED10: J14.3; also elsewhere on the board
/LED11: J15.3; also elsewhere on the board
/LED12: J17.3; also elsewhere on the board
/LED13: J18.3; also elsewhere on the board
/LED14: J19.3; also elsewhere on the board
GND: C31.2, C32.2, C33.2, C34.2, C35.2, C36.2, C37.2, C38.2, C39.2, C46.2, C47.2, C48.2, J7.1, J8.1, J9.1, J10.1, J11.1, J12.1, J13.1, J14.1, J15.1, J17.1, J18.1, J19.1; also elsewhere on the board

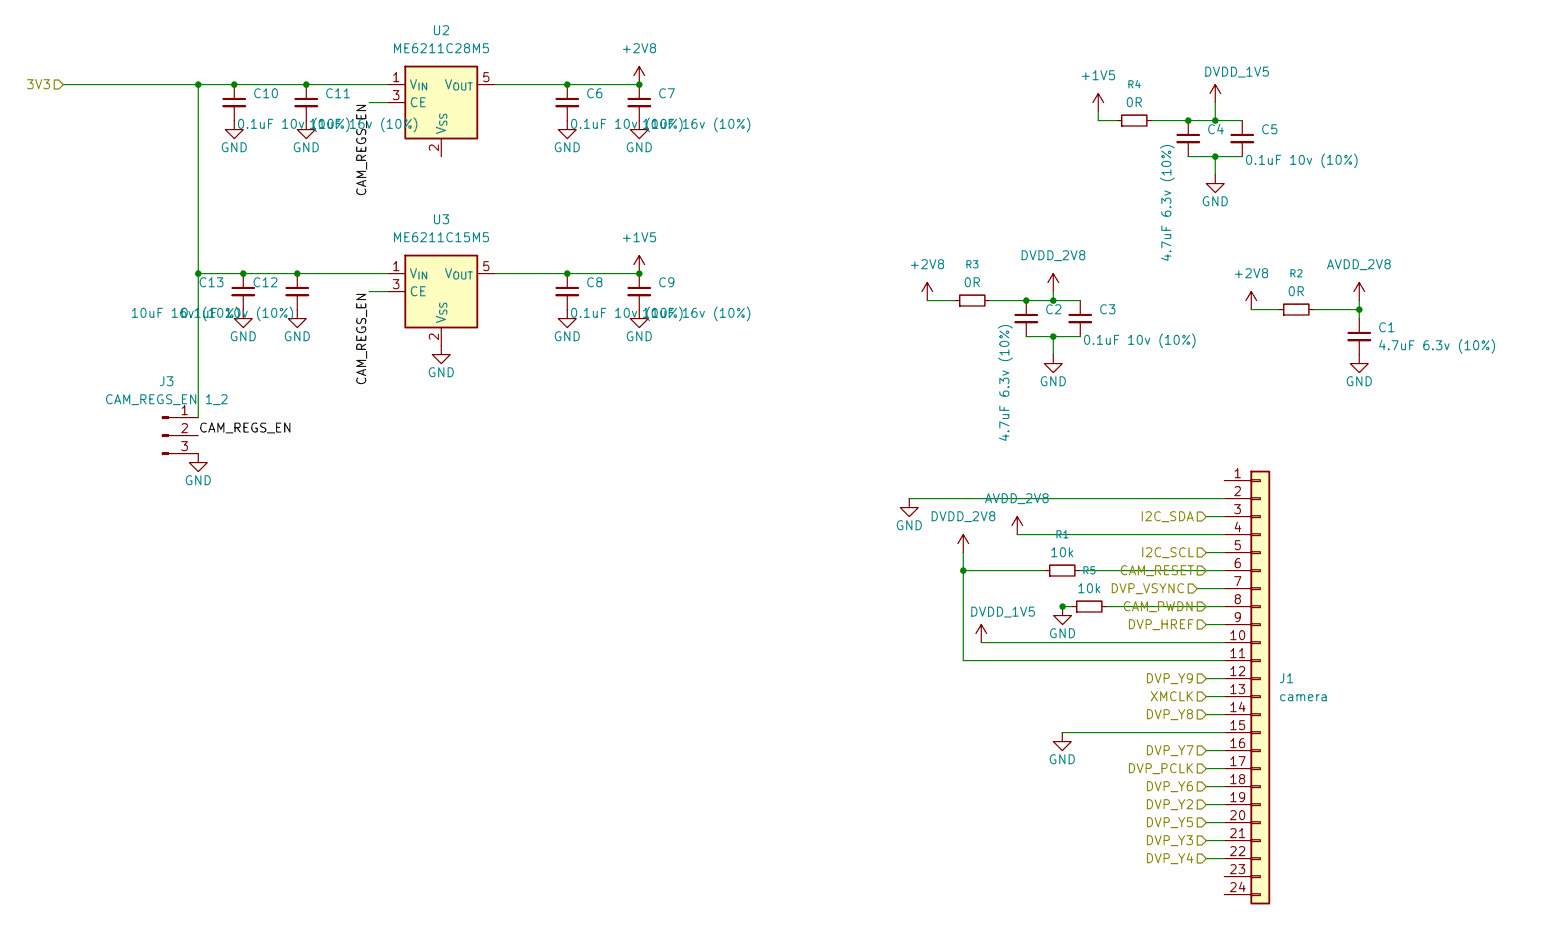
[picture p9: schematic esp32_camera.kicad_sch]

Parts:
C1, C2, C4: 4.7uF 6.3v (10%); C_0402_1005Metric
C3, C5, C6, C8, C10, C12: 0.1uF 10v (10%); C_0402_1005Metric
C7, C9, C11, C13: 10uF 16v (10%); C_0603_1608Metric
J1: camera; FPC_1x24_P0.5mm_Horizontal_DualContact
J3: CAM_REGS_EN 1_2; PinHeader_1x03_P2.00mm_Vertical
R1, R5: 10k; R_0603_1608Metric
R2, R3, R4: 0R; R_0402_1005Metric
U2: ME6211C28M5; SOT-23-5
U3: ME6211C15M5; SOT-23-5

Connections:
+1V5: C8.1, C9.1, R4.1, U3.5 (V_{OUT})
+2V8: C6.1, C7.1, R2.1, R3.1, U2.5 (V_{OUT})
+3V3: C10.1, C11.1, C12.1, C13.1, J3.1, U2.1 (V_{IN}), U3.1 (V_{IN}); also elsewhere on the board
/DVP_HREF: J1.9; also elsewhere on the board
/DVP_PCLK: J1.17; also elsewhere on the board
/DVP_VSYNC: J1.7; also elsewhere on the board
/DVP_Y2: J1.19; also elsewhere on the board
/DVP_Y3: J1.21; also elsewhere on the board
/DVP_Y4: J1.22; also elsewhere on the board
/DVP_Y5: J1.20; also elsewhere on the board
/DVP_Y6: J1.18; also elsewhere on the board
/DVP_Y7: J1.16; also elsewhere on the board
/DVP_Y8: J1.14; also elsewhere on the board
/DVP_Y9: J1.12; also elsewhere on the board
/I2C_SCL: J1.5; also elsewhere on the board
/I2C_SDA: J1.3; also elsewhere on the board
/IO15: J1.13; also elsewhere on the board
/esp32_camera/CAM_PWDN: J1.8, R5.2
/esp32_camera/CAM_REGS_EN: J3.2, U2.3 (CE), U3.3 (CE)
/esp32_camera/CAM_RESET: J1.6, R1.2
AVDD_2V8: C1.1, J1.4, R2.2
DVDD_1V5: C4.1, C5.1, J1.10, R4.2
DVDD_2V8: C2.1, C3.1, J1.11, R1.1, R3.2
GND: C1.2, C2.2, C3.2, C4.2, C5.2, C6.2, C7.2, C8.2, C9.2, C10.2, C11.2, C12.2, C13.2, J1.2, J1.15, J3.3, R5.1, U3.2 (V_{SS}); also elsewhere on the board

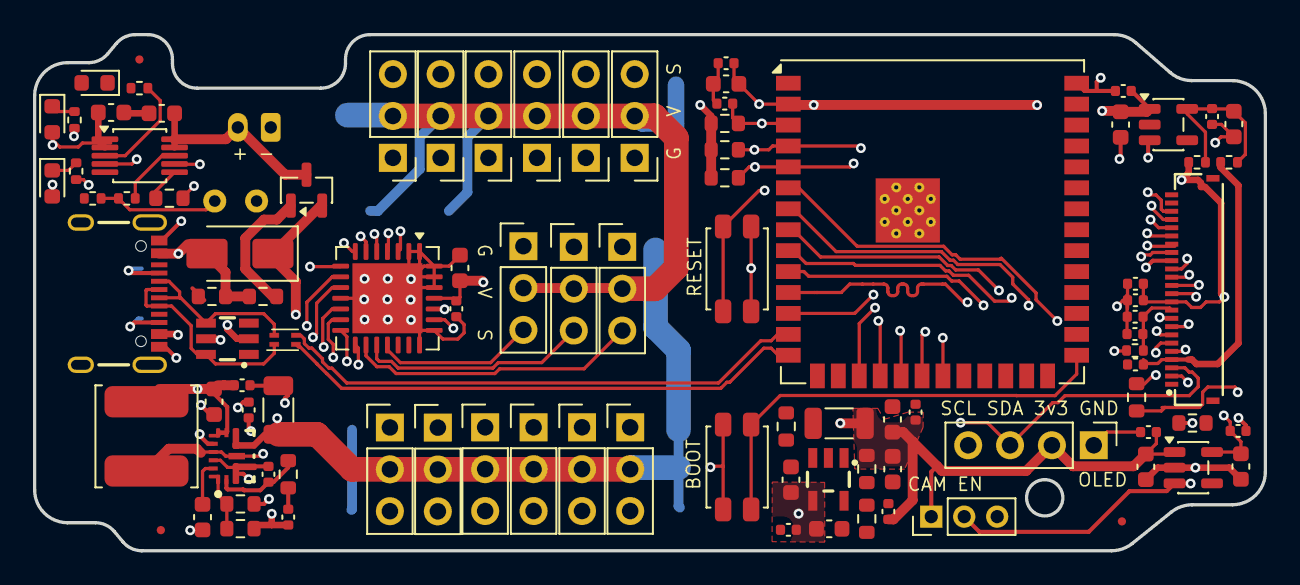
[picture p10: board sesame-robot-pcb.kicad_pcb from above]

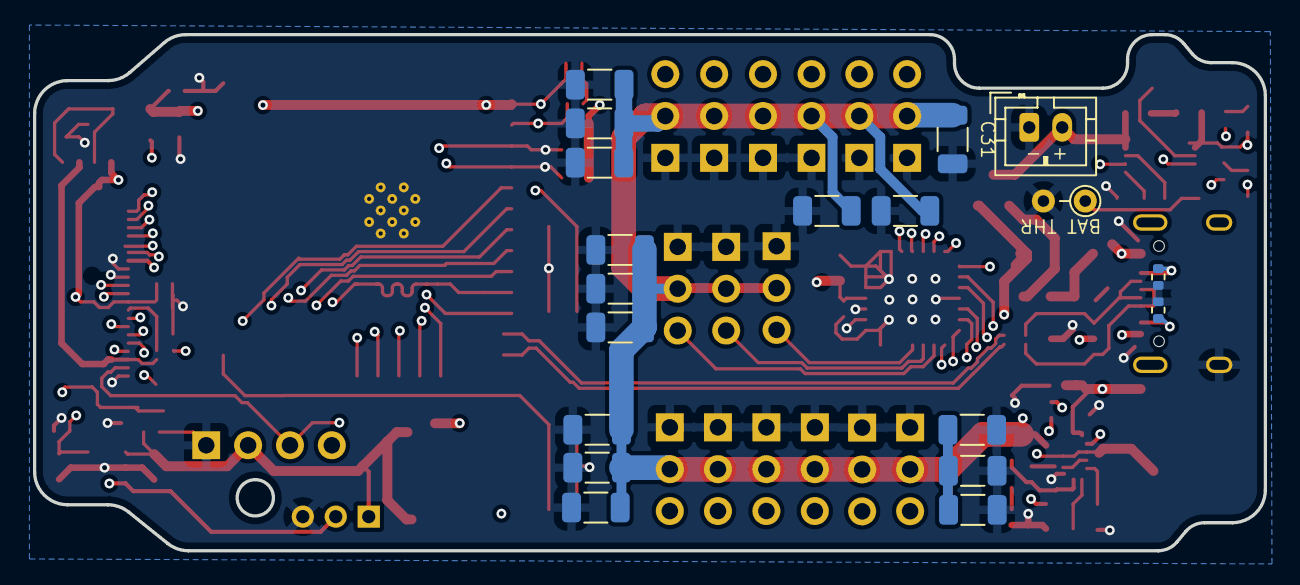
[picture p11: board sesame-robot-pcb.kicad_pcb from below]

Board: 4 copper layers, 74.7 x 31.3 mm, 115 parts (19 on the bottom side), 70 nets.

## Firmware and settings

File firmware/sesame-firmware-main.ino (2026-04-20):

// ── Board Selection ───────────────────────────────────────────────────────────
// Uncomment the line that matches your hardware before flashing.
// Leave all lines commented out to default to the Lolin S2 Mini.
//
// #define BOARD_ESP32CAM        // AI-Thinker ESP32-CAM  (uses PCA9685 servos)
// #define BOARD_ESP32S3CAM      // Generic ESP32-S3-CAM  (uses PCA9685 servos)
// #define BOARD_DISTRO_V2       // Sesame Distro Board V2 (ESP32-S3)
// #define BOARD_DISTRO_V1       // Sesame Distro Board V1 (ESP32-WROOM32)
// ─────────────────────────────────────────────────────────────────────────────

// Set to 0 to disable all Serial output (saves RAM/CPU when no UART connected)
#define ENABLE_SERIAL 0

// Set to 1 to automatically release PCA9685 servo outputs while resting.
// This reduces idle servo power draw by removing holding torque.
#define ENABLE_SERVO_AUTO_RELEASE 1

#if ENABLE_SERIAL
  #define DBG_BEGIN(baud) Serial.begin(baud)
  #define DBG_PRINT(...)  Serial.print(__VA_ARGS__)
  #define DBG_PRINTLN(...) Serial.println(__VA_ARGS__)
  #define DBG_PRINTF(...) Serial.printf(__VA_ARGS__)
#else
  #define DBG_BEGIN(baud) do {} while(0)
  #define DBG_PRINT(...)  do {} while(0)
  #define DBG_PRINTLN(...) do {} while(0)
  #define DBG_PRINTF(...) do {} while(0)
#endif

#include "hal/hal.h"

#include "soc/rtc_cntl_reg.h"
#include "soc/soc.h"

#include <WiFi.h>
#include <WebServer.h>
#include <DNSServer.h>
#include <ESPmDNS.h>
#include <ArduinoOTA.h>
#include <Wire.h>
#include <Preferences.h>
#if USE_PCA9685
  #include <Adafruit_PWMServoDriver.h>
#else
  #include <ESP32Servo.h>
#endif
#include <Adafruit_GFX.h>
#include <Adafruit_SSD1306.h>
#include "face-bitmaps.h"
#include "movement-sequences.h"
#include "captive-portal.h"
#include "camera-stream.h"

// --- Access Point Configuration ---
// This is the network the Robot will create
#define AP_SSID  "Sesame-Controller"
#define AP_PASS  "12345678" // Must be at least 8 characters

// --- Station Mode Configuration ---
// Stored in NVS, configurable from the web UI Settings panel.
// These defaults are used on first boot (before any NVS data exists).
String staSSID = "";
String staPass = "";
bool   staEnabled = false;

#define SCREEN_WIDTH 128
#define SCREEN_HEIGHT 64
#define OLED_RESET -1
#define OLED_I2C_ADDR 0x3C

// DNS Server for Captive Portal
DNSServer dnsServer;
const byte DNS_PORT = 53;

Adafruit_SSD1306 display(SCREEN_WIDTH, SCREEN_HEIGHT, &Wire, OLED_RESET);
bool oledAvailable = false;
WebServer server(80);

// Global state for animations
String currentCommand = "";
String currentFaceName = "default";
const unsigned char* const* currentFaceFrames = nullptr;
uint8_t currentFaceFrameCount = 0;
uint8_t currentFaceFrameIndex = 0;
unsigned long lastFaceFrameMs = 0;
int faceFps = 8;
FaceAnimMode currentFaceMode = FACE_ANIM_LOOP;
int8_t faceFrameDirection = 1;
bool faceAnimFinished = false;
int currentFaceFps = 0;
bool idleActive = false;
bool idleBlinkActive = false;
unsigned long nextIdleBlinkMs = 0;
uint8_t idleBlinkRepeatsLeft = 0;

// WiFi Info Scrolling
unsigned long lastInputTime = 0;
bool firstInputReceived = false;
bool showingWifiInfo = false;
int wifiScrollPos = 0;
unsigned long lastWifiScrollMs = 0;
String wifiInfoText = "";

// Network Mode
bool networkConnected = false;
IPAddress networkIP;
String deviceHostname = "sesame-robot";

// Camera LED state (used only when CAM_PIN_LED is available on a board).
bool cameraLedOn = false;

#if HAS_CAMERA
// Keep camera at active frame interval briefly after movement stops.
static unsigned long cameraFastUntilMs = 0;
static const unsigned long CAMERA_POST_MOVE_FAST_MS = 30000;
#endif

// ── Servo / PCA9685 ──────────────────────────────────────────────────────────
// Pin numbers correspond to ESP32 GPIO pins and differ between boards.
// For PCA9685 boards (ESP32-CAM, ESP32-S3-CAM) the driver is initialised in
// setup(); servo channels 0-7 map directly to PCA9685 outputs 0-7.
// For direct-PWM boards the servoPins array selects the GPIO for each channel.
// ─────────────────────────────────────────────────────────────────────────────
#if USE_PCA9685
  Adafruit_PWMServoDriver pwmDriver = Adafruit_PWMServoDriver(PCA9685_I2C_ADDR);
#else
  Servo servos[8];
  // Sesame Distro Board V2 Pinout
  //const int servoPins[8] = {4, 5, 6, 7, 15, 16, 17, 18};

  // Sesame Distro Board Pinout
  //const int servoPins[8] = {15, 2, 23, 19, 4, 16, 17, 18};

  // Lolin S2 Mini Pinout
  const int servoPins[8] = {1, 2, 4, 6, 8, 10, 13, 14};
#endif

// Subtrim values for each servo (offset in degrees)
int8_t servoSubtrim[8] = {0, 0, 0, 0, 0, 0, 0, 0};

// Per-channel calibration limits (microseconds).
// Adjust these per-servo to define the pulse width endpoints.
// angle 0° → servoMinUs[ch], angle 180° → servoMaxUs[ch].
//                             R1    R2    L1    L2    R4    R3    L3    L4
uint16_t servoMinUs[8]   = { 500,  500,  500,  500,  500,  500,  500,  500};
uint16_t servoMaxUs[8]   = {2500, 2500, 2500, 2500, 2500, 2500, 2500, 2500};

// Per-channel angle limits (degrees) — collision avoidance.
// Commanded angles are clamped to this range before µs mapping.
//                             R1   R2   L1   L2   R4   R3   L3   L4
uint8_t servoMinAngle[8] = {  0,   0,   0,   0,   0,   0,   0,   0};
uint8_t servoMaxAngle[8] = {180, 180, 180, 180, 180, 180, 180, 180};

// Current servo positions (degrees) — updated by setFrame/setServoAngle
int16_t servoFrameBuf[8] = {90,90,90,90,90,90,90,90};

// Animation constants
int frameDelay = 100;
int walkCycles = 10;
int motorCurrentDelay = 20; // ms delay between motor movements to prevent over-current

struct FaceEntry {
  const char* name;
  const unsigned char* const* frames;
  uint8_t maxFrames;
};

static const uint8_t MAX_FACE_FRAMES = 6;

#define MAKE_FACE_FRAMES(name) \
  const unsigned char* const face_##name##_frames[] = { \
    epd_bitmap_##name, epd_bitmap_##name##_1, epd_bitmap_##name##_2, \
    epd_bitmap_##name##_3, epd_bitmap_##name##_4, epd_bitmap_##name##_5 \
  };

#define X(name) MAKE_FACE_FRAMES(name)
FACE_LIST
#undef X
#undef MAKE_FACE_FRAMES

const FaceEntry faceEntries[] = {
#define X(name) { #name, face_##name##_frames, MAX_FACE_FRAMES },
  FACE_LIST
#undef X
  { "default", face_defualt_frames, MAX_FACE_FRAMES }
};

struct FaceFpsEntry {
  const char* name;
  uint8_t fps;
};

const FaceFpsEntry faceFpsEntries[] = {
  { "walk", 1 },
  { "rest", 1 },
  { "swim", 1 },
  { "dance", 1 },
  { "wave", 1 },
  { "point", 5 },
  { "stand", 1 },
  { "cute", 1 },
  { "pushup", 1 },
  { "freaky", 1 },
  { "bow", 1 },
  { "worm", 1 },
  { "shake", 1 },
  { "shrug", 1 },
  { "dead", 2 },
  { "crab", 1 },
  { "idle", 1 },
  { "idle_blink", 7 },
  { "default", 1 },
  // Conversational faces (manually controlled by Python - no auto-animation)
  { "happy", 1 },
  { "talk_happy", 1 },
  { "sad", 1 },
  { "talk_sad", 1 },
  { "angry", 1 },
  { "talk_angry", 1 },
  { "surprised", 1 },
  { "talk_surprised", 1 },
  { "sleepy", 1 },
  { "talk_sleepy", 1 },
  { "love", 1 },
  { "talk_love", 1 },
  { "excited", 1 },
  { "talk_excited", 1 },
  { "confused", 1 },
  { "talk_confused", 1 },
  { "thinking", 1 },
  { "talk_thinking", 1 },
};


// Prototypes
void setServoAngle(uint8_t channel, int angle);
void updateFaceBitmap(const unsigned char* bitmap);
void setFace(const String& faceName);
void setFaceMode(FaceAnimMode mode);
void setFaceWithMode(const String& faceName, FaceAnimMode mode);
void updateAnimatedFace();
void delayWithFace(unsigned long ms);
void enterIdle();
void exitIdle();
void updateIdleBlink();
int getFaceFpsForName(const String& faceName);
bool pressingCheck(const String& cmd, int ms);
#if USE_PCA9685 && ENABLE_SERVO_AUTO_RELEASE
void maybeAutoReleaseServos();
#endif
void handleGetSettings();
void handleSetSettings();
void handleGetStatus();
void handleApiCommand();
void updateWifiInfoScroll();
void recordInput();

bool cameraLedAvailable() {
#if defined(CAM_PIN_LED) && CAM_PIN_LED >= 0
  return true;
#else
  return false;
#endif
}

void applyCameraLed(bool on) {
#if defined(CAM_PIN_LED) && CAM_PIN_LED >= 0
  digitalWrite(CAM_PIN_LED, on ? HIGH : LOW);
#endif
}

void handleRoot() {
  server.send_P(200, "text/html", index_html);
}

void handleCommandWeb() {
  // We send 200 OK immediately so the web browser doesn't hang waiting for animation to finish
  if (server.hasArg("pose")) {
    currentCommand = server.arg("pose");
    recordInput();
    exitIdle();
    server.send(200, "text/plain", "OK"); 
  } 
  else if (server.hasArg("go")) {
    currentCommand = server.arg("go");
    recordInput();
    exitIdle();
    server.send(200, "text/plain", "OK");
  } 
  else if (server.hasArg("stop")) {
    currentCommand = "";
    recordInput();
    server.send(200, "text/plain", "OK");
  }
  else if (server.hasArg("reboot")) {
    server.send(200, "text/plain", "Rebooting...");
    delay(200);
    ESP.restart();
  }
  else if (server.hasArg("motor") && server.hasArg("value")) {
    int motorNum = server.arg("motor").toInt();
    int servoIdx = servoNameToIndex(server.arg("motor"));
    int angle = server.arg("value").toInt();
    if (motorNum >= 1 && motorNum <= 8 && angle >= 0 && angle <= 180) {
      setServoAngle(motorNum - 1, angle); // Convert 1-based to 0-based index
      recordInput();
      server.send(200, "text/plain", "OK");
    } else if (servoIdx != -1 && angle >= 0 && angle <= 180) {
      setServoAngle(servoIdx, angle);
      recordInput();
      server.send(200, "text/plain", "OK");
    } else {
      server.send(400, "text/plain", "Invalid motor or angle");
    }
  }
  else {
    server.send(400, "text/plain", "Bad Args");
  }
}

void handleGetSettings() {
  char buf[256];
  int n = snprintf(buf, sizeof(buf),
    "{\"frameDelay\":%d,\"walkCycles\":%d,\"motorCurrentDelay\":%d,"
    "\"faceFps\":%d,\"staSSID\":\"%s\",\"staEnabled\":%s,\"networkConnected\":%s,"
    "\"cameraEnabled\":%s",
    frameDelay, walkCycles, motorCurrentDelay, faceFps,
    staSSID.c_str(), staEnabled ? "true" : "false", networkConnected ? "true" : "false",
#if HAS_CAMERA
    cameraEnabled ? "true" : "false"
#else
    "false"
#endif
    );
  if (networkConnected) {
    n += snprintf(buf + n, sizeof(buf) - n, ",\"networkIP\":\"%s\"", networkIP.toString().c_str());
  }
  n += snprintf(buf + n, sizeof(buf) - n,
    ",\"cameraLed\":%s,\"cameraLedAvailable\":%s",
    cameraLedOn ? "true" : "false",
    cameraLedAvailable() ? "true" : "false");
  snprintf(buf + n, sizeof(buf) - n, "}");
  server.send(200, "application/json", buf);
}

void handleSetSettings() {
  if (server.hasArg("frameDelay")) frameDelay = server.arg("frameDelay").toInt();
  if (server.hasArg("walkCycles")) walkCycles = server.arg("walkCycles").toInt();
  if (server.hasArg("motorCurrentDelay")) motorCurrentDelay = server.arg("motorCurrentDelay").toInt();
  if (server.hasArg("faceFps")) faceFps = (int)max(1L, server.arg("faceFps").toInt());
#if HAS_CAMERA
  if (server.hasArg("camera")) {
    cameraEnabled = (server.arg("camera") == "1");
    // Persist camera state to NVS
    Preferences prefs;
    prefs.begin("wifi", false);
    prefs.putBool("camOn", cameraEnabled);
    prefs.end();
  }
#endif
  if (server.hasArg("camLed")) {
    cameraLedOn = (server.arg("camLed") == "1");
    applyCameraLed(cameraLedOn);
  }
  server.send(200, "text/plain", "OK");
}

void handleSetWifi() {
  if (server.hasArg("ssid")) staSSID = server.arg("ssid");
  if (server.hasArg("pass")) staPass = server.arg("pass");
  staEnabled = (staSSID.length() > 0);
  // Save to NVS
  Preferences prefs;
  prefs.begin("wifi", false);
  prefs.putString("ssid", staSSID);
  prefs.putString("pass", staPass);
  prefs.putBool("enabled", staEnabled);
  prefs.end();
  server.send(200, "text/plain", "OK — reboot to connect");
}

void loadWifiFromNVS() {
  Preferences prefs;
  prefs.begin("wifi", true);
  if (prefs.isKey("ssid")) {
    staSSID   = prefs.getString("ssid", "");
    staPass   = prefs.getString("pass", "");
    staEnabled = prefs.getBool("enabled", false);
  }
#if HAS_CAMERA
  cameraEnabled = prefs.getBool("camOn", true);
#endif
  prefs.end();
}

void handleGetCalibration() {
  char buf[320];
  int n = snprintf(buf, sizeof(buf), "{\"min\":[%u,%u,%u,%u,%u,%u,%u,%u],"
    "\"max\":[%u,%u,%u,%u,%u,%u,%u,%u],"
    "\"angleMin\":[%u,%u,%u,%u,%u,%u,%u,%u],"
    "\"angleMax\":[%u,%u,%u,%u,%u,%u,%u,%u],"
    "\"pos\":[%d,%d,%d,%d,%d,%d,%d,%d]}",
    servoMinUs[0],servoMinUs[1],servoMinUs[2],servoMinUs[3],servoMinUs[4],servoMinUs[5],servoMinUs[6],servoMinUs[7],
    servoMaxUs[0],servoMaxUs[1],servoMaxUs[2],servoMaxUs[3],servoMaxUs[4],servoMaxUs[5],servoMaxUs[6],servoMaxUs[7],
    servoMinAngle[0],servoMinAngle[1],servoMinAngle[2],servoMinAngle[3],servoMinAngle[4],servoMinAngle[5],servoMinAngle[6],servoMinAngle[7],
    servoMaxAngle[0],servoMaxAngle[1],servoMaxAngle[2],servoMaxAngle[3],servoMaxAngle[4],servoMaxAngle[5],servoMaxAngle[6],servoMaxAngle[7],
    servoFrameBuf[0],servoFrameBuf[1],servoFrameBuf[2],servoFrameBuf[3],servoFrameBuf[4],servoFrameBuf[5],servoFrameBuf[6],servoFrameBuf[7]);
  server.send(200, "application/json", buf);
}
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
void loop() {
  // Handle OTA updates
  ArduinoOTA.handle();

  // Process DNS requests for captive portal
  dnsServer.processNextRequest();
  
  server.handleClient();
  updateAnimatedFace();
  updateIdleBlink();
  updateWifiInfoScroll();
#if USE_PCA9685
  flushServoFrame();
#endif

  if (currentCommand != "") {
#if HAS_CAMERA
    cameraMoving = true;
    cameraFastUntilMs = millis() + CAMERA_POST_MOVE_FAST_MS;
#endif
    String cmd = currentCommand;
    if (cmd == "forward") runWalkPose();
    else if (cmd == "backward") runWalkBackward();
    else if (cmd == "left") runTurnLeft();
    else if (cmd == "right") runTurnRight();
    else if (cmd == "rest") { runRestPose(); if (currentCommand == "rest") currentCommand = ""; }
    else if (cmd == "stand") { runStandPose(1); if (currentCommand == "stand") currentCommand = ""; }
    else if (cmd == "wave") runWavePose();
    else if (cmd == "dance") runDancePose();
    else if (cmd == "swim") runSwimPose();
    else if (cmd == "point") runPointPose();
    else if (cmd == "pushup") runPushupPose();
    else if (cmd == "bow") runBowPose();
    else if (cmd == "cute") runCutePose();
    else if (cmd == "freaky") runFreakyPose();
    else if (cmd == "worm") runWormPose();
    else if (cmd == "shake") runShakePose();
    else if (cmd == "shrug") runShrugPose();
    else if (cmd == "dead") runDeadPose();
    else if (cmd == "crab") runCrabPose();
  }
#if HAS_CAMERA
  else {
    cameraMoving = ((int32_t)(cameraFastUntilMs - millis()) > 0);
  }
#endif

#if USE_PCA9685 && ENABLE_SERVO_AUTO_RELEASE
  maybeAutoReleaseServos();
#endif
  
  // Serial CLI for debugging (can be used to diagnose servo position issues and wiring)
#if ENABLE_SERIAL
  if (Serial.available()) {
    static char command_buffer[32];
    static byte buffer_pos = 0;
    char c = Serial.read();
    if (c == '\n' || c == '\r') {
      if (buffer_pos > 0) {
        command_buffer[buffer_pos] = '\0';
        int motorNum, angle;
        recordInput();
        if(strcmp(command_buffer, "run walk") == 0 || strcmp(command_buffer, "rn wf") == 0) { currentCommand = "forward"; runWalkPose(); currentCommand = ""; }
        else if(strcmp(command_buffer, "rn wb") == 0) { currentCommand = "backward"; runWalkBackward(); currentCommand = ""; }
        else if(strcmp(command_buffer, "rn tl") == 0) { currentCommand = "left"; runTurnLeft(); currentCommand = ""; }
        else if(strcmp(command_buffer, "rn tr") == 0) { currentCommand = "right"; runTurnRight(); currentCommand = ""; }
        else if(strcmp(command_buffer, "run rest") == 0 || strcmp(command_buffer, "rn rs") == 0) runRestPose();
        else if(strcmp(command_buffer, "run stand") == 0 || strcmp(command_buffer, "rn st") == 0) runStandPose(1);
        else if(strcmp(command_buffer, "rn wv") == 0) { currentCommand = "wave"; runWavePose(); }
        else if(strcmp(command_buffer, "rn dn") == 0) { currentCommand = "dance"; runDancePose(); }
        else if(strcmp(command_buffer, "rn sw") == 0) { currentCommand = "swim"; runSwimPose(); }
        else if(strcmp(command_buffer, "rn pt") == 0) { currentCommand = "point"; runPointPose(); }
        else if(strcmp(command_buffer, "rn pu") == 0) { currentCommand = "pushup"; runPushupPose(); }
        else if(strcmp(command_buffer, "rn bw") == 0) { currentCommand = "bow"; runBowPose(); }
        else if(strcmp(command_buffer, "rn ct") == 0) { currentCommand = "cute"; runCutePose(); }
        else if(strcmp(command_buffer, "rn fk") == 0) { currentCommand = "freaky"; runFreakyPose(); }
        else if(strcmp(command_buffer, "rn wm") == 0) { currentCommand = "worm"; runWormPose(); }
        else if(strcmp(command_buffer, "rn sk") == 0) { currentCommand = "shake"; runShakePose(); }
        else if(strcmp(command_buffer, "rn sg") == 0) { currentCommand = "shrug"; runShrugPose(); }
        else if(strcmp(command_buffer, "rn dd") == 0) { currentCommand = "dead"; runDeadPose(); }
        else if(strcmp(command_buffer, "rn cb") == 0) { currentCommand = "crab"; runCrabPose(); }
        else if (strcmp(command_buffer, "subtrim") == 0 || strcmp(command_buffer, "st") == 0) {
          DBG_PRINTLN("Subtrim values:");
          for (int i = 0; i < 8; i++) {
            DBG_PRINT("Motor "); DBG_PRINT(i); DBG_PRINT(": ");
            if (servoSubtrim[i] >= 0) DBG_PRINT("+");
            DBG_PRINTLN(servoSubtrim[i]);
          }
        }
        else if (strcmp(command_buffer, "subtrim save") == 0 || strcmp(command_buffer, "st save") == 0) {
          DBG_PRINTLN("Copy and paste this into your code:");
          DBG_PRINT("int8_t servoSubtrim[8] = {");
          for (int i = 0; i < 8; i++) {
            DBG_PRINT(servoSubtrim[i]);
            if (i < 7) DBG_PRINT(", ");
          }
          DBG_PRINTLN("};");
        }
        else if (strncmp(command_buffer, "subtrim reset", 13) == 0 || strncmp(command_buffer, "st reset", 8) == 0) {
          for (int i = 0; i < 8; i++) servoSubtrim[i] = 0;
          DBG_PRINTLN("All subtrim values reset to 0");
        }
        else if (strncmp(command_buffer, "subtrim ", 8) == 0 || strncmp(command_buffer, "st ", 3) == 0) {
          const char* params = (command_buffer[1] == 't') ? command_buffer + 3 : command_buffer + 8;
          int trimMotor, trimValue;
          if (sscanf(params, "%d %d", &trimMotor, &trimValue) == 2) {
            if (trimMotor >= 0 && trimMotor < 8) {
              if (trimValue >= -90 && trimValue <= 90) {
                servoSubtrim[trimMotor] = trimValue;
                DBG_PRINT("Motor "); DBG_PRINT(trimMotor); DBG_PRINT(" subtrim set to ");
                if (trimValue >= 0) DBG_PRINT("+");
                DBG_PRINTLN(trimValue);
              } else {
                DBG_PRINTLN("Subtrim value must be between -90 and +90");
              }
            } else {
              DBG_PRINTLN("Invalid motor number (0-7)");
            }
          }
        }
        // --- Calibration (per-servo min/max angle) ---
        else if (strcmp(command_buffer, "cal") == 0) {
          DBG_PRINTLN("Calibration (us + angle limits):");
          for (int i = 0; i < 8; i++) {
            DBG_PRINT("  "); DBG_PRINT(ServoNames[i]); DBG_PRINT(" (ch"); DBG_PRINT(i);
            DBG_PRINT("): us="); DBG_PRINT(servoMinUs[i]);
            DBG_PRINT("-"); DBG_PRINT(servoMaxUs[i]);
            DBG_PRINT("  angle="); DBG_PRINT(servoMinAngle[i]);
            DBG_PRINT("-"); DBG_PRINTLN(servoMaxAngle[i]);
          }
        }
        else if (strcmp(command_buffer, "cal save") == 0) {
          DBG_PRINTLN("Copy and paste this into your code:");
          DBG_PRINT("uint16_t servoMinUs[8]   = {");
          for (int i = 0; i < 8; i++) { DBG_PRINT(servoMinUs[i]); if (i < 7) DBG_PRINT(", "); }
          DBG_PRINTLN("};");
          DBG_PRINT("uint16_t servoMaxUs[8]   = {");
          for (int i = 0; i < 8; i++) { DBG_PRINT(servoMaxUs[i]); if (i < 7) DBG_PRINT(", "); }
          DBG_PRINTLN("};");
        }
        else if (strncmp(command_buffer, "cal reset", 9) == 0) {
          for (int i = 0; i < 8; i++) { servoMinUs[i] = 500; servoMaxUs[i] = 2500; servoMinAngle[i] = 0; servoMaxAngle[i] = 180; }
          DBG_PRINTLN("All calibration reset to 500-2500us, 0-180deg");
        }
        else if (strncmp(command_buffer, "cal ", 4) == 0) {
          int calCh, calMin, calMax;
          if (sscanf(command_buffer + 4, "%d %d %d", &calCh, &calMin, &calMax) == 3) {
            if (calCh >= 0 && calCh < 8 && calMin >= 500 && calMax <= 2500 && calMin < calMax) {
              servoMinUs[calCh] = calMin;
              servoMaxUs[calCh] = calMax;
              DBG_PRINT(ServoNames[calCh]); DBG_PRINT(" cal set to min=");
              DBG_PRINT(calMin); DBG_PRINT("us max="); DBG_PRINT(calMax); DBG_PRINTLN("us");
            } else {
              DBG_PRINTLN("Usage: cal <ch 0-7> <min 500-2499> <max 501-2500>");
            }
          }
        }
        else if (strncmp(command_buffer, "all ", 4) == 0) {
             if (sscanf(command_buffer + 4, "%d", &angle) == 1) {
                 for (int i = 0; i < 8; i++) setServoAngle(i, angle);
                 DBG_PRINT("All servos set to "); DBG_PRINTLN(angle);
             }
        }
        else if (sscanf(command_buffer, "%d %d", &motorNum, &angle) == 2) {
             if (motorNum >= 0 && motorNum < 8) {
                 setServoAngle(motorNum, angle);
                 DBG_PRINT("Servo "); DBG_PRINT(motorNum); DBG_PRINT(" set to "); DBG_PRINTLN(angle);
             } else {
                 DBG_PRINTLN("Invalid motor number (0-7)");
             }
        }
        buffer_pos = 0;
      }
    } else if (buffer_pos < sizeof(command_buffer) - 1) {
      command_buffer[buffer_pos++] = c;
    }
  }
#endif
}
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

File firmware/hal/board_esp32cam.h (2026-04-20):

#pragma once

// =============================================================================
// HAL: ESP32-CAM (AI-Thinker)
// =============================================================================
//
// Board: AI-Thinker ESP32-CAM (ESP32 module with OV2640 camera)
// Arduino IDE board target: "AI Thinker ESP32-CAM"
//
// ── I2C Bus ──────────────────────────────────────────────────────────────────
// GPIO 26 (SIOD) and GPIO 27 (SIOC) are the OV2640 camera's SCCB lines.
// They are routed only to the camera FFC connector on the PCB and are NOT
// brought out to the external J2/J3 header pins, so an external I2C device
// cannot be connected to them.
//
// The accessible header pins on the AI-Thinker ESP32-CAM are:
//   J3: 5V  GND  IO12  IO13  IO15  IO14  IO2  IO4
//   J2: 3V3 GND  IO16  IO0   IO3   IO1   GND  5V
//
// GPIO pins excluded from I2C use:
//   GPIO  0 — boot-mode strapping (must be HIGH; LOW = download mode)
//   GPIO  1 — serial TX (UART0)
//   GPIO  2 — SD_DATA0, strapping pin (must be LOW / floating at boot)
//   GPIO  3 — serial RX (UART0)
//   GPIO  4 — SD_DATA1; drives the on-board flash LED HIGH
//   GPIO 12 — SD_DATA2, strapping pin (must be LOW at boot w/ 4 MB PSRAM)
//   GPIO 16 — connected to PSRAM /CS on this module; do not reassign
//
// Remaining header pins eligible for I2C:
//   GPIO 13 — SD_DATA3    (no boot constraint)
//   GPIO 14 — SD_CLK      (no boot constraint)           ← chosen SDA
//   GPIO 15 — SD_CMD      (must be HIGH at boot) ← chosen SCL
//             Internal pull-up keeps GPIO 15 HIGH during boot,
//             which is compatible with the I2C SCL idle state.
//
// Trade-off: SD_CLK and SD_CMD are consumed by I2C, so the SD card cannot
// operate simultaneously.  The four SD data lines (GPIO 2, 4, 12, 13) are
// preserved and SD can be re-enabled by swapping back to ESP32Servo/direct PWM.
//
// ── SD-Card Pins ─────────────────────────────────────────────────────────────
//   SD_DATA0 → GPIO 2   SD_DATA1 → GPIO 4
//   SD_DATA2 → GPIO 12  SD_DATA3 → GPIO 13  ← preserved
//   SD_CLK   → GPIO 14                       ← used as I2C SDA
//   SD_CMD   → GPIO 15                       ← used as I2C SCL
//
// ── Servo Driver ─────────────────────────────────────────────────────────────
// The camera occupies all four LEDC timer groups that ESP32Servo needs, so
// direct PWM servo output is not possible on this board.  A PCA9685 I2C PWM
// driver is used instead.
//
// PCA9685 pulse-width mapping (50 Hz / 4096 ticks):
//   SERVOMIN 150 ticks ≈  732 µs  (matches existing firmware MIN_PULSE)
//   SERVOMAX 600 ticks ≈ 2929 µs  (matches existing firmware MAX_PULSE)
//
// ── Strapping / Boot Pins (do not reassign) ──────────────────────────────────
//   GPIO  0 — boot-mode select (LOW = download mode)
//   GPIO  2 — must be LOW or floating at boot (SD_DATA0 / pull-down)
//   GPIO 12 — must be LOW at boot when PSRAM is present (1.8 V select)
//   GPIO 15 — must be HIGH at boot (SD_CMD / internal pull-up)
// =============================================================================

// ── I2C ──────────────────────────────────────────────────────────────────────
// GPIO 14 (SD_CLK) as SDA and GPIO 15 (SD_CMD) as SCL — both physically
// accessible on the J3 header; no critical boot-strapping conflicts.
#define I2C_SDA 14
#define I2C_SCL 15

// ── PCA9685 servo driver ─────────────────────────────────────────────────────
#define USE_PCA9685        1
#define PCA9685_I2C_ADDR   0x40

// Pulse-width tick counts for the PCA9685 (27 MHz oscillator, prescale 131).
// Actual period ≈ 20.024 ms → 4.889 µs/tick.
// Conservative range matching MF90 datasheet: 500–2500 µs.
#define PCA9685_SERVOMIN   102   //  ≈  500 µs  (102 × 4.889 µs)
#define PCA9685_SERVOMAX   511   //  ≈ 2500 µs  (511 × 4.889 µs)

// ── Camera (OV2640) ──────────────────────────────────────────────────────────
#define HAS_CAMERA         1
#define CAM_PIN_PWDN       32
#define CAM_PIN_RESET      -1
#define CAM_PIN_XCLK        0
#define CAM_PIN_SIOD       26
#define CAM_PIN_SIOC       27
#define CAM_PIN_D7         35
#define CAM_PIN_D6         34
#define CAM_PIN_D5         39
#define CAM_PIN_D4         36
#define CAM_PIN_D3         21
#define CAM_PIN_D2         19
#define CAM_PIN_D1         18
#define CAM_PIN_D0          5
#define CAM_PIN_VSYNC      25
#define CAM_PIN_HREF       23
#define CAM_PIN_PCLK       22

// On-board white LED (flash LED) on AI-Thinker ESP32-CAM.
#define CAM_PIN_LED         4

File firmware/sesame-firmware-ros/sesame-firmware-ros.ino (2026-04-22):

// =============================================================================
// Sesame Robot — micro-ROS Firmware
// =============================================================================
//
// This firmware variant replaces the HTTP/captive-portal stack with a
// micro-ROS node that communicates with a host computer running:
//   • micro-ROS Agent (UDP bridge, port 8888)
//   • sesame_aruco ArUco detection node
//   • sesame_aruco navigation node
//
// Flash this sketch to an AI-Thinker ESP32-CAM (BOARD_ESP32CAM) or a
// compatible ESP32-S3-CAM board (BOARD_ESP32S3CAM).  Do NOT flash it to
// Distro V1/V2 or Lolin S2 Mini boards — they have no camera.
//
// Build with:
//   pio run -e esp32cam_ros   (or esp32s3cam_ros)
//
// WiFi + Agent configuration
// ──────────────────────────
// Defaults below are compile-time overrides.  The firmware also reads the
// same NVS namespace ("wifi") used by the standard firmware, so credentials
// already saved there are reused automatically.
//
// To configure via serial (115200 baud):
//   set ssid   <yourSSID>
//   set pass   <yourPassword>
//   set agent  <agentIP>
//   set port   <agentPort>
//   save
//
// ROS Topics
// ──────────
//   Publishes:
//     /camera/image_raw   sensor_msgs/CompressedImage   (JPEG, ~5–15 KB)
//     /sesame/status      std_msgs/String               (JSON)
//
//   Subscribes:
//     /sesame/cmd         std_msgs/String   ("forward","backward","left",
//                                           "right","rest","stand","wave",
//                                           "dance","swim","point","pushup",
//                                           "bow","cute","freaky","worm",
//                                           "shake","shrug","dead","crab",
//                                           "stop")
//     /sesame/pose        geometry_msgs/PoseStamped     (from ArUco node)
//
// Architecture
// ────────────
//   Core 0: camera_task — grabs JPEG frames, copies to shared double-buffer
//   Core 1: ros_spin_task (priority 5) — micro-ROS executor + publishers
//           movement_task (priority 2)  — executes pose commands, OLED anim
// =============================================================================

// ---------------------------------------------------------------------------
// Compile-time configuration (overridden by NVS at runtime)
// ---------------------------------------------------------------------------
#define DEFAULT_WIFI_SSID    ""          // Your network SSID
#define DEFAULT_WIFI_PASS    ""          // Your network password
#define DEFAULT_AGENT_IP     "192.168.1.100"
#define DEFAULT_AGENT_PORT   8888

// Camera frame size for micro-ROS publishing.
// QVGA (320×240) JPEG is typically 5–15 KB which fits in the default
// micro-ROS transport buffers after configuring colcon.meta.
// Drop to FRAMESIZE_QQVGA (160×120) if you see serialisation errors.
#define CAM_FRAMESIZE        FRAMESIZE_QVGA
#define CAM_JPEG_QUALITY     20          // Lower = better quality / larger file

// Maximum JPEG buffer size (bytes) allocated in PSRAM.
// Must be >= typical JPEG output at the chosen resolution.
#define MAX_JPEG_SIZE        (24 * 1024)

// Interval between camera publishes (ms).  100 ms ≈ 10 fps.
#define CAM_PUBLISH_INTERVAL_MS  100

// Interval between /sesame/status publishes (ms).
#define STATUS_PUBLISH_INTERVAL_MS  1000

// Set to 1 to enable Serial debug output.
#define ENABLE_SERIAL        0

// Set to 1 to automatically release PCA9685 servo outputs while resting.
#define ENABLE_SERVO_AUTO_RELEASE  1

// ---------------------------------------------------------------------------
// Debug macros
// ---------------------------------------------------------------------------
#if ENABLE_SERIAL
  #define DBG_BEGIN(baud)      Serial.begin(baud)
  #define DBG_PRINT(...)       Serial.print(__VA_ARGS__)
  #define DBG_PRINTLN(...)     Serial.println(__VA_ARGS__)
  #define DBG_PRINTF(...)      Serial.printf(__VA_ARGS__)
#else
  #define DBG_BEGIN(baud)      do {} while (0)
  #define DBG_PRINT(...)       do {} while (0)
  #define DBG_PRINTLN(...)     do {} while (0)
  #define DBG_PRINTF(...)      do {} while (0)
#endif

// ---------------------------------------------------------------------------
// Board HAL and firmware headers
// ---------------------------------------------------------------------------
#include "hal/hal.h"
#include "face-bitmaps.h"
#include "movement-sequences.h"

// ---------------------------------------------------------------------------
// Arduino / ESP-IDF system headers
// ---------------------------------------------------------------------------
#include "soc/rtc_cntl_reg.h"
#include "soc/soc.h"

#include <Arduino.h>
#include <WiFi.h>
#include <Wire.h>
#include <Preferences.h>
#include <freertos/FreeRTOS.h>
#include <freertos/task.h>
#include <freertos/semphr.h>
#include <freertos/queue.h>

#if USE_PCA9685
  #include <Adafruit_PWMServoDriver.h>
#endif
#include <Adafruit_GFX.h>
#include <Adafruit_SSD1306.h>

#if HAS_CAMERA
  #include "esp_camera.h"
#endif

// ---------------------------------------------------------------------------
// micro-ROS headers
// ---------------------------------------------------------------------------
#include <micro_ros_arduino.h>
#include <rcl/rcl.h>
#include <rcl/error_handling.h>
#include <rclc/rclc.h>
#include <rclc/executor.h>
#include <rmw_microros/rmw_microros.h>

#include <sensor_msgs/msg/compressed_image.h>
#include <std_msgs/msg/string.h>
#include <geometry_msgs/msg/pose_stamped.h>
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

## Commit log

2026-03-25 Add tutorial button to README
    Added a tutorial button and updated the greeting.
2026-03-29 Fix duplicate Tutorial button
2026-04-13 Add HAL files for ESP32-CAM and ESP32-S3-CAM with PCA9685 servo driver support
    Agent-Logs-Url: https://github.com/sasensio/sesame-robot/sessions/312de17f-44b5-4109-b239-108d2f71cb64
2026-04-16 Fix ESP32-CAM I2C pins to use accessible header pins GPIO 14/15 instead of internal camera SCCB GPIO 26/27
    Agent-Logs-Url: https://github.com/sasensio/sesame-robot/sessions/0998b293-fa4c-4913-8a36-1bcec4ed07fb
    [board_esp32cam.h]
2026-04-19 added esp23-cam carrier
    [carriers.3mf, esp_carrier.stl, main_carrier.stl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]
2026-04-20 feat: improve camera reliability, reduce servo idle power, and add LED control
    - add optional PCA9685 servo auto-release to reduce idle power draw on camera boards
    - keep camera in high-FPS mode for 30 seconds after movement stops
    - harden camera OFF->ON lifecycle with deinit, delayed power-up, reinit retries, and frame-failure recovery
    - add camera LED support in HAL, firmware settings API, and web UI toggle near camera control
    - improve web stream reconnect behavior with cache-busted URLs and retry cleanup
    - update firmware and HAL documentation for new camera/servo behavior and settings endpoints
    - adapt gitignore rules for PlatformIO, FreeCAD, and KiCad generated/local files
    - include sy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
    [bom.csv, carriers.3mf, designators.csv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]
2026-04-22 feat: implement micro-ROS firmware + ArUco positioning ROS 2 package
    Agent-Logs-Url: https://github.com/sasensio/sesame-robot/sessions/51159b44-d19c-4aed-acf7-b9300434286d
    [camera_calibration.yaml]

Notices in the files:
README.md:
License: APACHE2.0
